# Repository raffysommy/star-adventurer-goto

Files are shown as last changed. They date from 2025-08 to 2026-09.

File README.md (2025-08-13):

# Star Adventurer Classic and 2i GoTo Mod

This project transforms a Sky-Watcher Star Adventurer or Star Adventurer 2i into a fully functional GoTo mount with guiding capabilities. It achieves this by adding a custom, Arduino-powered Declination (DEC) axis that works in tandem with the mount's native Right Ascension (RA) motor.

The system is controlled via a Python-based proxy server that emulates the Meade LX200 protocol, allowing you to control your modified mount from most popular planetarium or astrophotography software (like Stellarium, Cartes du Ciel) using INDI LX200 GPS driver (it may work on Windows too).

The core of this project relies on the [**advanced firmware**](https://skywatcher.com/post/resource/star-adventurer-advanced-firmware/) for the Star Adventurer (not needed for the 2i), which enables serial communication. This firmware is a bit buggy, and this project includes several software workarounds to ensure stable and reliable operation despite those quirks.

## Features

-   **Full GoTo Capability:** Slew to any celestial object from your favorite software.
    
-   **LX200 Protocol Emulation:** Wide compatibility with astrophotography software.
    
-   **Full Guiding Support:** Pulse guiding on both RA and DEC axes (via direct driving or  ST4).

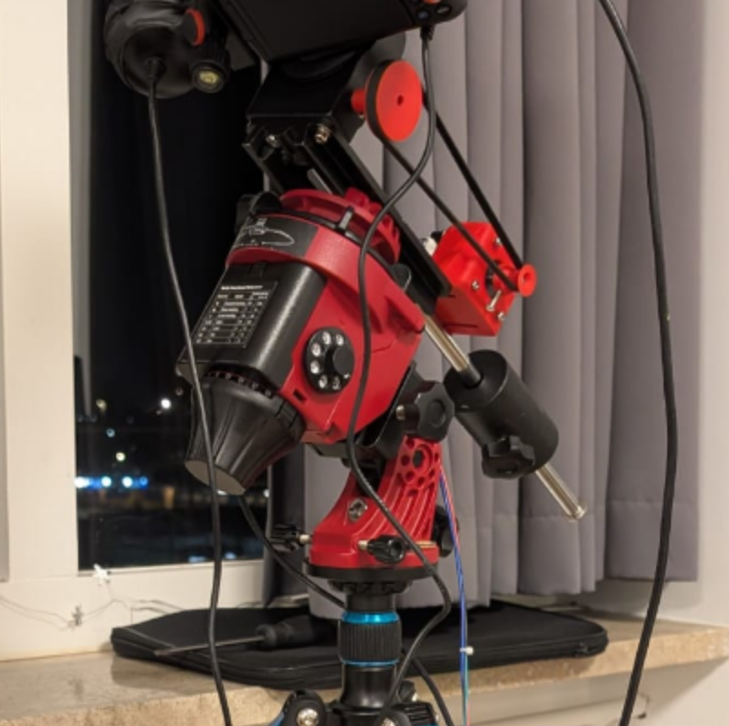
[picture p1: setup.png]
Setup


## 1. Hardware Requirements

### Electronic Components

The heart of the DEC axis is a simple circuit controlled by an Arduino Nano.

-   **Arduino Nano:** The microcontroller that runs the DEC motor logic.
    
-   **EasyDriver v4.5 (or similar):** A simple stepper motor driver.
    
-   **NEMA 17 Bipolar Stepper Motor:** The motor that drives the DEC axis.
    
-   **DC Female Power Jack:** To power the EasyDriver and motor (9-12V recommended). A step-up converter can be used if you are powering from a 5V source.
    
-   **(Optional) RJ12 Socket:** For a standard ST4 guiding port. The system also supports direct pulse guiding commands from your control software.

### 3D Printed Parts (`/stl` folder)

You will need to print the following parts to assemble the DEC axis.

-   `Nema17MotorHolder.stl`: Mounts the NEMA 17 motor to the Star Adventurer's DEC bracket.
    
    -   Requires: 4x M3 screws (for the motor) and 2x M5 screws with bolts (for the bracket).
        
-   `StarAdventurerDeclinationKnobMod.stl`: Replaces the original DEC knob on the Star Adventurer and connects to the timing belt.
    
    -   Requires: 1x small M2 screw to secure it.
        
-   `Nema17Knob.stl`: Attaches to the NEMA 17 motor shaft.
    
    -   Requires: 1x M3 screw and nut for tightening.

### Mechanical Parts

-   **GT2 Timing Belt (400mm loop, 6mm width):** Connects the motor to the declination knob.

## 2. Wiring and Assembly

The circuit connects the Arduino to the EasyDriver to control the stepper motor. It's crucial to ensure all ground connections (GND) are common between the Arduino, the EasyDriver, and the DC power supply.

-   **Power:** Connect your 9-12V DC power supply to the EasyDriver's power input (M+ and GND).
    
-   **Arduino to EasyDriver:**
    
    -   Connect Arduino **Pin D2** to EasyDriver **STEP**.
        
    -   Connect Arduino **Pin D3** to EasyDriver **DIR**.
        
    -   Connect Arduino **GND** to EasyDriver **GND** (the one near the power input).
        
-   **Motor to EasyDriver:** Connect the four wires of the NEMA 17 motor to the EasyDriver's motor outputs (OUT1A, OUT1B, OUT2A, OUT2B).

#### Circuit Diagram

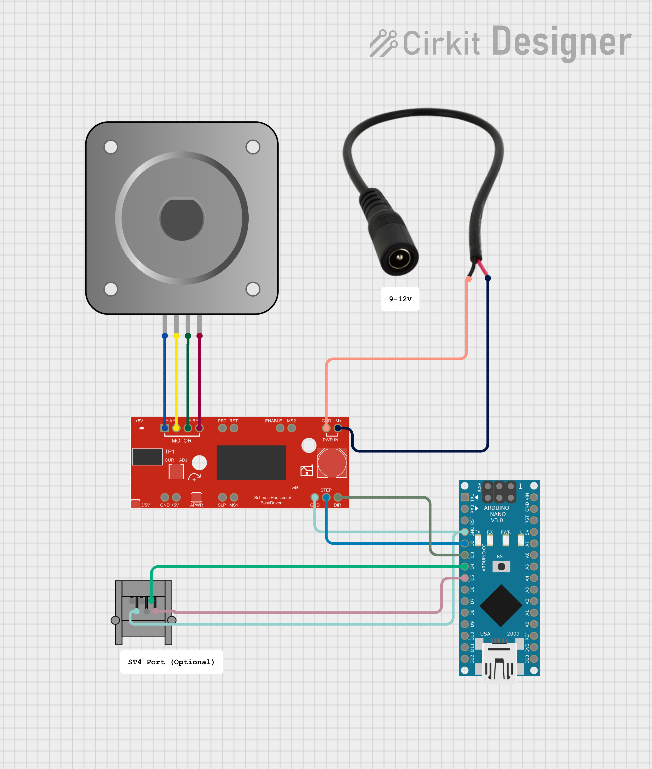
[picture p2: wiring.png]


## 3. Software Setup and Installation

### Step 1: Clone the Repository

First, clone this repository to your local machine.

```
git clone https://github.com/raffysommy/star-adventurer-goto
cd star-adventurer-goto

```

### Step 2: Set up the Arduino

1.  Open the Arduino IDE.
    
2.  Navigate to the `arduino` folder in this project.
    
3.  Open the `.ino` sketch file.
    
4.  Connect your Arduino Nano to your computer.
    
5.  Select the correct board (Arduino Nano) and COM/TTY port from the `Tools` menu.
    
6.  Upload the sketch to the Arduino.

### Step 3: Install Python Dependencies

It is highly recommended to use a Python virtual environment.

```
# Create a virtual environment (optional but recommended)
python -m venv venv
source venv/bin/activate  # On Windows use `venv\Scripts\activate`

# Install the required packages
pip install -r requirements.txt

```

## 4. Configuration

Before running the server, you must configure the Python script with your specific setup.

Open the `lx200.py` file and edit the following constants at the top:

-   **`SERIAL_PORT`**: Change this to the serial port your Arduino is connected to (e.g., `COM3` on Windows, `/dev/ttyUSB1` on Linux).
    
-   **`OBSERVER_LON`**: Set your observer's longitude in decimal degrees (East is positive).
    
-   **`OBSERVER_LAT`**: Set your observer's latitude in decimal degrees (North is positive).

**Initial Pier Side**: You may need to set your mount's starting pier side. In `new_lx200.py`, find the `TelescopeController` class and its `__init__` method. Set the `self.is_pier_east_side` variable according to your physical setup.
-- **Example:** Set `pier_east_side = False` (the default) if the  camera is on the side of the Star Adventurer with the mode dial and lights, with your camera pointing in the opposite direction of the celestial pole. Set it to `True` if the lights are on the other side or you are pointing towards the celestial pole. If you make it wrong the mount will move in the opposite direction, so just try to flip it :)

You may also need to adjust `step_per_rev_dec` if your motor or gearing setup is different.

## 5. Advanced Topics & Explanation

### The RA Slew Limitation and the "Virtual Meridian Flip"

The advanced firmware for the Star Adventurer has a critical limitation: the RA motor cannot perform a full 360-degree slew. It operates reliably only within a ~180-degree range of motion in software counters. If a GoTo command requires it to move beyond this range (i.e., to cross a "virtual bar"), the command will fail, and the mount will get stuck.

This script implements a "hack" to overcome this. We call it a **Virtual Meridian Flip**.

Here's how it works:

1.  When your planetarium software (e.g., KStarsr) sends a GoTo command, our Python proxy receives the target's RA and DEC coordinates.
    
2.  The script calculates the target's Hour Angle (HA), which determines its position relative to the meridian.
    
3.  The script checks if slewing to this HA would force the RA motor to cross its "forbidden zone".
    
4.  If it does, the script performs a "virtual meridian flip":
    
    -   It calculates a new RA target that is 180 degrees away from the original target's HA. This new target is within the motor's "safe" operational range.
        
    -   It simultaneously inverts the target DEC coordinate.
        
    -   It sends these _new, corrected_ coordinates to the mount's motors.

The result is that the telescope ends up pointing at the correct celestial object, but with the mount on the opposite side of the pier, completely avoiding the firmware limitation. This entire process is transparent to your control software, which believes it's communicating with a standard, fully-functional LX200 mount.

### Networking the Star Adventurer (for non-2i models)

The original Star Adventurer communicates via a serial (USB) port. The Star Adventurer 2i has built-in WiFi. For this system to work, the Python proxy script needs to communicate with the mount over a network connection.

-   **Star Adventurer 2i users:** You can skip this step. Simply connect to your mount's WiFi network.
    
-   **Original Star Adventurer users:** You must make the mount's serial port available on the network. The recommended tool for this on Linux-based systems (like a Raspberry Pi) is `ser2net`.

`ser2net` is a daemon that allows you to connect to a serial port over a TCP or UDP network socket.

**Example `ser2net` Configuration:**

You need to create or edit the `/etc/ser2net.yaml` file. Here is a sample configuration that exposes a serial device on `UDP port 1880`, which is what the `synscan` library expects.

```
%YAML 1.1
---
# This is a ser2net configuration file.
# Find detailed documentation in ser2net.yaml(5)

define: &banner \r\nser2net port \p device \d [\B] (Debian GNU/Linux)\r\n\r\n

connection: &con0096
    accepter: udp,1880
    enable: on
    options:
      kickolduser: true
      telnet-brk-on-sync: false
    connector: serialdev,
              /dev/ttyUSB0,
              115200n81,local

```

**Breakdown of the configuration:**

-   `accepter: udp,1880`: Listens for incoming UDP connections on port 1880.
    
-   `connector: serialdev, /dev/ttyUSB0, 115200n81,local`: Forwards all traffic from the network port to the serial device located at `/dev/ttyUSB0` with a baud rate of 115200. **You must change `/dev/ttyUSB0`** to match the actual device name of your Star Adventurer's USB-to-Serial adapter.

After configuring `ser2net`, you can enable and start the service using `systemctl`:

```
sudo systemctl enable ser2net
sudo systemctl start ser2net

```

## 6. Running the Proxy Server

Once everything is configured, run the main script from your terminal:

```
python lx200.py

```

If successful, you will see a message indicating that the proxy is listening for connections:

LX200 Proxy listening on 127.0.0.1:5000

The server is now running. You can now connect to it from your planetarium or astrophotography software by configuring it to use a **Meade** LX200 **GPS** telescope at **IP Address `127.0.0.1`** and **Port `5000`**.

Once connected, you can select objects and issue GoTo commands, and the mount will slew to the target

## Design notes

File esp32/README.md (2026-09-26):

# StarMount: ESP32-S3 mount controller

Firmware that turns an ESP32-S3 into the complete controller for the Star Adventurer
GoTo mod. It replaces the Raspberry Pi running `lx200.py` and the separate DEC
controller:

- **RA**: the Star Adventurer's own motor, over USB (the ESP is the USB host)
- **DEC**: the NEMA17 stepper on an EasyDriver, driven directly
- **Clients**: OnStep protocol over Wi-Fi, a superset of Meade LX200. INDI/Ekos and ASIAIR use their
  OnStep driver (pier side, meridian limits, backlash), NINA the ASCOM OnStep driver, and
  Stellarium, SkySafari and generic LX200 drivers work too. Plus a web dashboard.

## Hardware

| What | Details |
|---|---|
| Board | ESP32-S3 N16R8 (16 MB flash, 8 MB octal PSRAM) |
| RA link | Native USB port (OTG, GPIO19/20) ↔ mount's USB (Prolific PL2303 HXD, `067b:2303`), 115200 8N1 |
| VBUS | The ESP must supply 5 V on the OTG port: board powered from the 5V pin, "USB-OTG" pad bridged |
| DEC | EasyDriver: STEP GPIO6, DIR GPIO5, EN GPIO38 (active low, disabled while idle) |
| Ground | ESP, EasyDriver/12 V supply and mount share ground |

The OTG port belongs to the mount, so after the first flash **everything goes over Wi-Fi**:
updates, logs, control. The CH343 "UART" port shows the UART0 console if you can attach it.

## Build, flash, update

Needs PlatformIO ≥ 6.2 (the pioarduino platform, Arduino core 3.x / ESP-IDF 5.5, is pulled
in automatically).

```sh
cd esp32
# Wi-Fi credentials (git-ignored); without them the ESP opens AP "StarMount" / "starmount"
cat > secrets.ini <<'EOF'
[secrets]
build_flags = -DWIFI_SSID=\"MySSID\" -DWIFI_PASS=\"MyPassword\"
EOF

pio run -e usb -t upload            # first flash over USB (BOOT+RESET for download mode)
pio run -e ota -t upload            # later: ArduinoOTA to starmount.local
curl -F fw=@.pio/build/usb/firmware.bin http://starmount.local/update   # or HTTP upload
pio test -e native                  # host unit tests (no hardware)
```

**Recovery.** A new image that crashes before Wi-Fi comes up is meant to roll back to the previous
one, but it hasn't been checked that the bootloader actually has rollback enabled.
The USB host starts 10 s after boot, so OTA always has a window. Holding BOOT during that
window skips the USB host for one boot. Worst case: unplug the mount, BOOT+RESET, flash over USB.

**Tailscale / VPN.** If a VPN advertises the LAN subnet (Tailscale `--accept-routes`), traffic
to the ESP goes into the tunnel and it looks dead. Disable accept-routes, or bind to the
Wi-Fi interface (`curl --interface wlo1`, `STARMOUNT_IFACE=wlo1` for the tests).

## Interfaces

| Port / path | What |
|---|---|
| TCP 5001, 9999 | OnStepX-compatible commands (LX200 superset): see [docs/onstep-protocol.md](docs/onstep-protocol.md). 5001 is the old `lx200.py` port, 9999 OnStep's usual one |
| `http://starmount.local/` | Dashboard: RA/DEC, state, LST, clock, settings, DEC test buttons |
| `/api/status` | JSON state (used by the dashboard and the tests) |
| `/api/settings`, `/api/time`, `/api/home`, `/api/stop` | Settings, set clock from the browser, set RA home, stop |
| `/api/lx200?c=:GR` | Run one OnStep/LX200 command over HTTP |
| `/api/register`, `/api/goto_ha`, `/api/dec` | Debug: redefine the RA register, slew to a register angle, DEC test moves |
| TCP 10110 | NMEA over TCP: the GPS sentences, for INDI's "GPS NMEA" driver (KStars/Ekos time and location) |
| `/api/boots` | The last 10 boots (reset reason, how long the previous boot ran) and mount USB connects/disconnects, in NVS |
| `/api/tasks`, `/api/gps_nmea` | Per-task CPU/stack/heap; inject NMEA sentences (debug, no GPS needed) |
| `/log`, telnet 23 | Log (kept across resets: after a crash `/log` still shows the previous boot) |
| `/sys`, `/cmd?c=:e1`, `/update`, `/wifi` | System status, raw mount command, firmware upload, Wi-Fi setup |
| UDP 11880 | SynScan Wi-Fi-dongle compatible bridge to the mount (debugging only: it bypasses the RA controller) |

## Architecture

```
 clients:  INDI / NINA / ASIAIR / Stellarium / PHD2           browser
               │ OnStep (LX200 superset), TCP 5001 + 9999    │ HTTP
 ┌─────────────┴──────────────┐                  ┌───────────┴───────┐
 │ onstep_server              │                  │ dashboard         │  protocol
 │ parse, reply formats       │                  │ JSON API          │  front-ends
 └─────────────┬──────────────┘                  └───────────────────┘
 ┌─────────────┴──────────────┐
 │ mount: target, flip branch,│  one flip flag for the whole mount
 │ DEC reversal, guide, sync  │
 └──────┬──────────────┬──────┘
        │              │
 ┌──────┴──────┐ ┌─────┴──────┐        ┌───────────────────────────────┐
 │ ra_axis     │ │ dec_axis   │        │ lib/core/astro (pure C++)     │  pure logic,
 │ task + queue│ │ FastAccel- │ ◄────► │ LST, HA/RA, meridian flip,    │  host-tested
 │ tracking,   │ │ Stepper    │        │ DEC steps, OnStep parse/format│
 │ goto, guide │ └─────┬──────┘        └───────────────────────────────┘
 └──────┬──────┘       │
 ┌──────┴──────┐       │           services: clock (NTP / LX200 / browser → later GPS),
 │ skywatcher  │       │                     settings (NVS), netlog, OTA
 │ protocol    │       │
 ├─────────────┤       │
 │ mount_usb + │   EasyDriver
 │ pl2303      │   (DEC motor)
 └──────┬──────┘
    USB OTG → Star Adventurer (RA)
```

Design rules:

- **One owner per motor.** The `ra_axis` task is the only code that sends RA motion commands.
  Everything else posts requests to its queue, so commands can't interleave (that was
  `lx200.py`'s `ra_locker` and its "junk data" workarounds). `mount_usb` serializes the
  request/response pairs underneath.
- **Protocols are thin front-ends.** `onstep_server` only parses and formats. The mount-level
  state (target, meridian-flip branch, guide flags) lives in `mount`, shared by every
  front-end, so there is one flip flag whatever the client.
- **Math lives in `lib/core`** with no Arduino dependencies. It is unit-tested on the PC against
  golden values produced by `lx200.py`'s own functions (`test/gen_golden.py`).
- **Guiding is never disturbed.** Pulses change only the RA step period while the motor keeps
  running. DEC pulses are exact step moves. Recovery from firmware auto-stops uses a bare
  `J`, never a stop/restart.
- **Cores:** Wi-Fi, lwIP and USB host on core 0; RA/DEC/OnStep server on core 1. DEC step pulses come from hardware.

Planned additions: GPS (time, site, magnetic declination), a 9-axis IMU in the base box
(polar axis altitude and heading) and a 6-axis IMU on the camera hot shoe (mechanical pose,
push-to, pier side, safety limits), plus fast polar alignment in tiers from sky-less
(~0.5–1°) to two plate solves (~1′). The design is in
[docs/sensors-and-alignment.md](docs/sensors-and-alignment.md).

## Star Adventurer firmware quirks (measured)

| Quirk | Handling |
|---|---|
| Motion mode `G` is two digits: `1x`=tracking slow, `3x`=tracking fast; `x0`=CW, `x1`=CCW (the fix in the modified pysynscan) | `sw::setMode` |
| `G` is refused (`!2`) while the motor runs | stop, poll `:f` until stopped, then G → I → J |
| Max RA speed ≈ 0.28°/s (~68× sidereal); T1 below ~6 or fast mode is not faster | slews use slow mode, T1 = 5 |
| At slew speed, CW auto-stops after ~0.8 s; after any direction reversal both directions stop after ~0.5 s | `J` re-sent every 400 ms during slews; in tracking, `:f` polled every 250 ms and a bare `J` sent if stopped |
| Register below 0 → tracking stalls every second; above ±241.7° the 24-bit register overflows | GoTo/sync targets limited to HA 2°–183° (`offset_star_adventurer` = 2°), overflowing register values refused |
| At power-on the mount starts tracking by itself, so the register isn't exactly 0 | a register within 1° of 0 = fresh mount → set to home (HA 2°) |

## Differences from lx200.py

- **LST is correct.** `lx200.py` gives ephem the longitude as a float (read as radians) and local
  time as UTC, so its sidereal time is off by a constant (~93° plus the timezone). A sync hid this
  for RA, but HA-based decisions moved: **the meridian flip now happens at the true meridian.**
- `:SG/:SL/:SC` set the clock (the Pi had its own). `:Sg/:St` parse signs correctly. `:GG` uses the
  Meade sign convention.
- `:MS`/`:CM` without a prior valid `:Sr` don't move or sync RA.
- **The protocol is OnStepX's** (since 2026-09-26), not `lx200.py`'s dialect. Set commands answer
  `1`/`0`, `:CM` answers `N/A#`, stops and pulses answer nothing, and `:GVP#` is `On-Step`.
  Standard LX200 clients don't notice. Tracking can be turned off (`:Td`/`:Te`).
- DEC guide pulses are exact step counts, not timed stops (those overshot by the queued steps).
- RA guide/slow-move directions follow ASCOM/EQMOD: west = 1.5×, east = 0.5× sidereal (`lx200.py`
  had them swapped). Redo PHD2 calibration made with the old firmware.
- DEC guide rate is 0.5× sidereal (1.7 steps/s). `lx200.py`'s "sidereal" 6.796 steps/s was really 2×.
- DEC backlash is compensated (below), and DEC GoTos always end moving north (+steps).
- **RA window and flip.** The register window starts at a configurable east limit (dashboard, NVS
  `ra_east`, default 0 = `lx200.py`'s flip at the meridian; −30 = flip 2 h before it). register =
  HA − east limit + 2°. GoTos use the window [2°, 182°] on either branch (`lx200.py` flipped at 180,
  leaving a 2° dead zone). Tracking goes on past the window and **stops at register 235°**, before
  the 24-bit overflow. Changing the east limit shifts the register so the position keeps its meaning.
- **Branch choice happens at use, not at `:Sr`.** `:MS` takes the window's branch, and `:CM` keeps
  the branch nearest the current register (a sync doesn't move the mount). Before, a sync past the
  window flipped the maths without moving: the old beyond-the-pole bug. DEC steps are computed then
  too, so the `:Sr`/`:Sd` order doesn't matter. The flip flag survives OTA and crash resets.
- The RA register survives ESP restarts (read back from the mount). The DEC position survives soft
  resets and OTA (kept in RAM). After a power-on DEC starts at 0° (146400 steps), as `lx200.py` did.

## Measured on the sky (2026-09-25, plate solves through a window)

M50 + 70-200 @ 200 mm (3.9″/px), astrometry.net 4100 indexes, scripts in `tools/sky/` (prototypes: ESP IP and `wlo1` are hard-coded in `pa.py`; run them from `$HOME`, gphoto2 is a snap)
(`pa.py`: polar alignment from two solves around an RA move; `mount_tests.py`: DEC, sync,
GoTo, guide, drift; `pe_record.py`: RA drift from live-view frames, no shutter).

| What | Result |
|---|---|
| DEC backlash | ~250 steps (0.30–0.34°) on every reversal, reproducible |
| DEC scale | 805 steps/° on one clean move (nominal 813.3) |
| RA/DEC orthogonality | 89.8° |
| RA GoTo after sync | 0.5–3′ (limited by the RA drift below) |
| DEC GoTo after sync | before: ~1′ if ending north, 17–18′ if ending south; with compensation: 0.4–1.4′ both ways |
| DEC guide pulses | before: the first ~4 pulses after a reversal did nothing; now the first one overshoots ~2× once, then settles |
| RA guide pulses | 0.45–0.6× sidereal (nominal 0.5×) |
| RA tracking (unguided, 10 min, 1 frame/min) | register exactly sidereal, but the sky wanders ±60″ — mechanical |
| RA periodic error (live view, 22 min, ~7 fps) | **±30″ sine at the worm period (~10 min)**, cycles correlate 0.89, 7″ rms non-periodic left. Max slope 0.3″/s: PHD2 + Predictive PEC; no firmware PEC (no worm index, phase lost at power-on) |

**DEC backlash model.** `dec_axis` keeps the motor position and the gear output apart: the gear
sits within `[motor − backlash, motor]` and only moves when pushed. Everything reported and
targeted is the gear position. On a reversal the play is run out at slew speed (guide pulses
included, so PHD2 sees no dead zone). `backlash` is a setting (dashboard, NVS key `dec_bl`,
default 250 steps); lowering it softens the one-pulse overshoot after a reversal.

## PEC, limits and GPS (2026-09-26)

- **PEC**, OnStep-style (`:$QZ+ - / Z ! ?`, `:VR`/`:WR`, `:GXE6/7/8`; the INDI OnStep PEC tab):
  - The table has one correction per worm segment (~1 sidereal s; 599 segments of 86,751 counts
    per 144-tooth worm turn), in register counts.
  - **Record** takes RA guide pulses for one worm turn (turn PHD2's Predictive PEC off). It is
    smoothed, its mean removed, and averaged with the previous table.
  - **Play** changes the RA step period each segment and carries the rounding into the next
    segment, so a whole turn is exact despite the coarse T1.
  - **Worm phase** follows every register rewrite (sync, home, east limit) and is saved to NVS
    every 10 s. After a power-on it is restored, on the assumption that the worm didn't turn
    while unpowered.
  - **Playback only starts after 60 s without guide pulses**, so PHD2 never sees PEC switch on mid-guiding.
- **Limits**:
  - GoTo is refused below the horizon limit (`:Sh`, code `1`) and above the overhead limit (`:So`, `2`).
  - Tracking stops `raWestMinutes` past the meridian on the flipped branch (`:SXEA`, default
    120, capped by the overflow). `:SXE9` sets the east limit.
- **GPS** (boilerplate until the module is wired: UART1 RX 17 / TX 18, 9600, any NMEA RMC+GGA):
  - Time is trusted below NTP and above clients.
  - A fix with ≥4 satellites and HDOP < 5 sets the site.
  - `:GU#` reports `S` while the GPS keeps the clock.
  - The sentences are relayed on TCP 10110.
  - Tested by injection.
- **Resources** (measured, guiding plus a client polling 10× faster than INDI):
  - core 0 6% busy, core 1 18% busy
  - 157 KB internal heap free, PSRAM unused

## Rates, refraction, limits (2026-09-26)

- **Tracking rates:**
  - sidereal, lunar, solar, King and custom (`:TQ :TL :TS :TK :ST`); not saved, sidereal at boot
  - The base is now true sidereal (`lx200.py`'s 0.004176 was a fixed "refracted" slow-down).
  - **Calibrated:** the SA's register runs at exactly timerHz / T1, within ±0.04% from T1 280 to
    439 (`test/hil/rate_calibration.py`, data in `rate_calibration.csv`). The earlier "lunar
    0.36% slow" and PEC's 1.04 gain were laptop-side HTTP timing. Rate tests now use the ESP's
    own register-read timestamp (`counts_ms` in `/api/status`).
- **Refraction** (`:Tr`/`:Tn`, default on, RA only; `:T2` dual axis is not supported):
  - Every 10 s the rate is scaled by d(apparent HA)/d(true HA) at the current pointing
    (Saemundsson's formula).
  - Examples: 0.99975 on the meridian at Dec +20, about 0.9985 at 20° altitude in the west.
- **Guide rate** is one setting for both axes (`:SX90,n#`, dashboard, 0.1–0.9×, default 0.5).
  - DEC backlash can be set from the client (`:$BD[arcsec]#`). RA backlash only accepts 0.
- **Axis limits** (`:GXEe/w` RA window in axis hour angle, `:GXEC/D` DEC mechanical, set with `:SXEx,n#`):
  - A GoTo past a DEC limit is refused with code `6`.
  - Manual moves stop at the limit, and guide pulses are clamped.
  - This is the counts-based layer of the collision limits.
- **PEC start rule** (default *strict*): playback starts only before guiding begins for the
  target (no pulse since boot or the last GoTo); otherwise it waits for the next GoTo.
  - Option: after 60 s without pulses.
  - A table recorded with a different segment count (it changed from 599 to 598 with true
    sidereal) is not loaded: record again.

## Manual moves and boot log (2026-09-27)

- **Manual moves** use OnStep's `:R0`–`:R9` (0.25×, 0.5×, 1×, 2×, 4×, 8×, 20×, 48×, half max, max;
  Meade `:RG :RC :RM :RS`):
  - RA below 1× changes only the tracking speed.
  - RA from 1×, the motor runs west (forward) or east (reversed) with the slew keep-alive.
    Max is ~64× measured, half max ~32×.
  - After a reversal the SA auto-stops once, and the tracking watchdog restarts it within seconds.
  - DEC runs up to 256× with the backlash take-up and axis limits.
  - Moves stop at the register limits, and abort a PEC recording.
- **Boot log** (`/api/boots`, shown on `/sys`), in NVS:
  - the last 10 boots: reset reason (`BROWNOUT` = rail sag, `power-on` = supply off), and how
    long the previous boot ran (saved every 5 min)
  - the last 10 mount USB connects/disconnects
  - Flash wear: one record per boot or event, plus 288 small writes a day.
- The PEC phase is now saved every 30 s, and only while a table exists.

## RA without a register limit, persistent state (2026-09-27)

- **Axis angle vs register.** The model (GoTo window, branch choice, sync, limits) works in
  the axis angle (= hour angle − east limit + 2°). The SA's register is bookkeeping:
  - register = axis angle + a persisted shift
  - It is re-centred to 8° whenever the motor is stopped anyway: sync, home, the start and end
    of a GoTo (a slew longer than the band re-centres mid-way).
  - **Never while tracking:** after ~15 h without a GoTo or sync, tracking stops at the band
    end instead of disturbing guiding.
  - The only RA limits are physical: the east limit, and the west tracking stop
    (`raWestMinutes`, default 120 = axis angle 242° with −30°; max 240 min).
- **Register writes are verified**: wait for the stop, write, read back, retry up to 3 times
  with a hard stop. The SA rejects `:E` while still stopping. It was seen twice in 20 writes
  after fast moves, and before this fix a sync could silently not apply. A write that still
  fails marks the position untrusted.
- **Sync keeps the branch nearest the current axis angle** (within 20°), even past a limit.
  Before, a sync exactly at the tracking stop picked the other branch.
- **Persistent state** (`persist.h`): one versioned struct in RTC memory holds the DEC
  position, the flip flag, the RA shift and "position trusted". It survives OTAs of *new*
  firmware (separate no-init variables moved whenever unrelated code changed), with no flash
  wear. It's lost on power-off, which resets the mount too.
- **Position trusted** (dashboard "NOT SYNCED"): false after a power-on (assumed home) or a
  failed register write, true after a confirmed sync.
- DEC continuous moves are bounded moves to the axis limit (exact stop even at 256×).

## Tests

- `pio test -e native`: astro math, DEC steps, parsing. Regenerate golden values with
  `python3 test/gen_golden.py` (needs `ephem`).
- `test/hil/` (hardware in the loop, against a running ESP and mount):
  - `guide_soak.py [N]`: random N/S/E/W pulse guiding; checks both axes moved exactly as
    commanded and that the RA motor was never restarted
  - `goto_test.py`: sync, then two combined RA+DEC GoTos and back. **Moves the mount.**
  - `pec_test.py`: records a synthetic periodic error from simulated guide pulses (one worm
    turn), checks the table, plays it back and checks that the register follows it (~17 min, RA tracking only).
    2026-09-26: table correlation 0.978, playback correlation 0.999, gain 1.04, 5.4 counts rms residual.
  - `features_test.py`: tracking rates, refraction, guide rate, backlash, DEC axis limits and
    the strict PEC rule (~3 min, small moves)
  - `rate_calibration.py`: RA register rate vs raw T1, timed on the ESP (~2.5 min per point)
  - `move_test.py`: manual-move speeds `:R0`–`:R9` on both axes (small moves, ~1 min)

  ```sh
  cd test/hil && STARMOUNT_HOST=starmount.local STARMOUNT_IFACE=wlo1 python3 guide_soak.py
  ```

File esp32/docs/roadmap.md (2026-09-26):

# Roadmap (as of 2026-09-26)

What's done, what to test on the sky, what to build next. The details are in
[sensors-and-alignment.md](sensors-and-alignment.md) (MEMS, alignment, collisions) and
[onstep-protocol.md](onstep-protocol.md) (the protocol).

## Done

- **Protocol:** OnStepX-compatible front-end (LX200 superset) on TCP 5001 and 9999, tested with
  the real INDI OnStep driver. It covers:
  - pier side
  - meridian and axis limits
  - backlash
  - PEC
  - tracking rates and refraction
  - GPS time/site (boilerplate)
- **RA:** a configurable register window (east limit −30° set; flip from 2 h before to ~1.5 h
  after the meridian), a tracking stop, and a sync that keeps the branch.
  - The register rate was calibrated: exactly timerHz/T1.
- **DEC:** backlash compensation (250 steps), GoTos finishing northward, 0.5× guide rate, axis limits.
- **PEC:** record from guide pulses, playback, the phase kept in NVS, and the strict start rule
  (never switches on under an active guider).
- **Sky tools** (`tools/sky`): polar alignment from two solves (`pa.py`), mount tests, a live-view
  periodic-error recorder. Measured: ±30″ worm PE (598 s), polar alignment down to ~11′.

## Next clear night (no new hardware)

1. **Re-sync first.** The mount was powered off since, and the DEC NOINIT position is lost
   whenever a firmware build changes the memory layout.
2. **Clearance check before the first GoTo east of the meridian** (east limit −30° is already set):
   - Camera body ~22° below horizontal on the east side and ~17° on the west side.
   - Swing the lens through its whole DEC range.
   - If anything touches: a smaller east limit, plus DEC axis limits on the dashboard.
3. **Ekos + PHD2 with the "LX200 OnStep" driver** (TCP `starmount.local:9999`):
   - Calibrate, then check PHD2's Guiding Assistant backlash against our 250 steps.
   - Go through a real meridian flip, and check that PHD2 flips its calibration from the reported pier side.
4. **Record a real PEC table:**
   - PHD2's Predictive PEC off, guide ≥1 worm turn (10 min), then Record in the INDI PEC tab or on the dashboard.
   - Next night: enable Play before starting guiding, and compare the RA RMS with and without it.
5. **NINA through the ASCOM OnStep driver** (Windows): connect, GoTo, sync, flip.
6. More DEC scale samples: one clean move gave 805 steps/° vs 813.3 nominal.

## Small firmware items (no hardware needed)

- ~~Reset-reason log~~: done 2026-09-27 (`/api/boots`, `/sys`). The "OTA power dips" of 2026-09-26
  were the user powering off. The 2026-09-23 offline event is still unexplained, and the log
  will tell next time.
- ~~Manual-move speeds~~: done 2026-09-27 (`:R0`–`:R9`, `test/hil/move_test.py`).
- PEC phase verification: after a power-on the restored phase is trusted as it is. It should be
  fitted against the first minutes of guiding without PEC (the first target of the night; PEC
  then plays from the next GoTo), and PEC refused if it doesn't match.
- ~~No register limit~~: done 2026-09-27 (axis angle vs register, re-centred only at stops,
  never while tracking; verified register writes; persistent-state struct).

## When the hardware arrives

Order from the design doc:
1. **GPS (GY-GPS6MV2)** on UART1: RX 17 ← GPS TX, TX 18 → GPS RX, 9600 baud. The firmware is ready:
   - check `/api/status` → `gps`
   - install `indi-gpsnmea` and point it at `starmount.local:10110`
   - test time in the field without NTP (`:GU#` shows `S`)
2. **Pi alignment tool:** turn `tools/sky/pa.py` into the T3/T2 tool (INDI + ASTAP + the ESP), with a live mode for turning the knobs.
   - Add a branch check at every sync from the solve's field rotation (180° apart on the two branches).
3. **Camera IMU (MPU6500, hot shoe)** on its own I2C bus: SDA 1, SCL 2, pull-ups at the ESP end.
   - mechanical pose at power-on and branch detection without sky
   - hand-slew detection and push-to
   - collision layers: accelerometer tilt rules, gyro stall detection during slews, taught limits
   - possibly exposed as OnStep "encoders"
   - **automatic DEC backlash and scale at startup** from the gyro (see the calibration table in the design doc)
4. **Base box IMU + magnetometer (LSM6DSV + QMC6309)**, I2C0 SDA 8 / SCL 9:
   - T0 polar alignment
   - knob feedback
   - tripod-bump detection
   - leveling (the tripod isn't level: turning the base changes the axis altitude)
5. Later / optional:
   - park and home from the IMU pose
   - pointing model from several syncs
   - BME280 for refraction and dew warnings
   - auto meridian flip once the collision limits exist

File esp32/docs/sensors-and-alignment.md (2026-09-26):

# Sensors, pose awareness and polar alignment

Design notes: what GPS and two IMUs can add to the ESP32 mount controller, what they
can't, and how they fit with the motor counts and plate solving. Nothing here is
implemented yet. See [README](../README.md) for what exists today.

## Goals

- **Pointing awareness:** a mount that knows where it is pointing, after assembly, after hand moves, on either side of the pier.
- **Fast manual pointing:** move it by hand (the RA motor tops out at ~0.28°/s, so 90° takes over 5 min) and let the ESP work out where it is.
- **Quick polar alignment good enough for guiding,** without the slow Ekos procedure. Precision on demand.
- **Never disturb tracking or guiding.**
- **Don't modify the Star Adventurer:** everything attaches outside (its USB port, the DEC knob belt, the battery bay).

## Constraints

- **The rig is disassembled for every trip.**
  - Nothing mechanical survives transport, so there's no fixed home and no park position to remember.
  - Only calibrations of *rigid* parts carry over.
- **Camera:** Canon M50 on a 70–200 at 200 mm. APS-C gives ~6.4° × 4.3° at ~3.8″/px.
  - The lens is held by its **tripod collar**, whose foot is screwed tightly to the DEC bracket's moving plate (minimal yaw).
  - The camera and lens can rotate *inside* the collar ring.
- **Clutches:** both can be released (RA on the Star Adventurer, DEC on the bracket), so both axes can be moved by hand.
- **Imaging host:** a Pi running INDI/Ekos, with ASTAP available for plate solving.
- **Polar alignment is manual:** the altitude and azimuth knobs have no motors, so "self alignment" means *guided* adjustment. Only motorised adjusters would make it automatic.
- **Power:** a USB-C power bank with a PD trigger set to 9 V.
  - 9 V feeds the EasyDriver directly.
  - A step-down converter feeds 5 V to the ESP, the Star Adventurer (through the OTG port's VBUS), the GPS and the IMUs.

## Hardware and placement

| Part | Where | Role |
|---|---|---|
| ESP32-S3, EasyDriver, GY-GPS6MV2 (u-blox NEO-6M), **LSM6DSV + QMC6309** magnetometer (one breakout) | **Base box**, ideally a keyed 3D-printed insert in the (empty) battery bay. That's the fixed body of the Star Adventurer, which tilts with the polar axis | Controller, time and site, polar-axis altitude and heading |
| **MPU6500** (6-axis) | **Camera hot shoe** | Mechanical pose of both axes, plate-solve-calibrated |

### IMU choices

- **Base: LSM6DSV + QMC6309.**
  - ~5× lower accelerometer noise and much lower temperature drift than the MPU6500, which keeps the magnetometer's tilt compensation accurate. Needed for sky-less polar alignment (T0 below).
  - A current part from real suppliers.
- **Camera: MPU6500 is enough.**
  - Its temperature drift (~0.5–1 mg/°C, up to ~0.5° over a night) is compensated with **its own on-chip temperature sensor**.
  - The model is learned from plate solves, and every solve re-anchors it.
  - The LSM6DSV's temperature wouldn't help: it measures the base box, not the lens.
- **Avoid the MPU9250.** It's discontinued, most boards sold as MPU9250 are clones or relabelled MPU6500/9255 dies without a working magnetometer, and even genuine ones have MPU6500-class accelerometers.

### Camera IMU placement: hot shoe vs collar ring

| | Hot shoe | Collar ring / foot (keyed clip) |
|---|---|---|
| IMU ↔ camera | Fixed. **Every plate solve calibrates the IMU directly** (offsets, temperature model) | Changes when the camera is rotated in the collar |
| IMU ↔ DEC axis | Changes with the collar rotation. **Re-measured per session by a short DEC move** (~10° in 10 s, gyro or two solves) | Fixed, calibrated once |
| Single-picture PA (T1) and IMU learning | Direct | Needs the camera ↔ collar roll per session |

**Decision: hot shoe**, with an automatic short DEC move at startup.
- If the camera is rotated in the collar during the night, the gyro sees a rotation about the optical axis while the motors are idle, and the ESP re-measures.
- The cable crosses both axes either way: leave a loose loop with slack for DEC passing the pole.

### Other hardware notes

- **EasyDriver stays.** It's disabled almost all night (a few slews, short guide pulses), so heat and power are not a concern, and the camera has never slipped with DEC unpowered.
  - A TMC2209 would be optional: silent, cool, holding current, StallGuard for belt-slip or collision detection.
  - Keep the IMU away from the driver chip anyway.
- **Magnetometer environment:** the EasyDriver's coil currents, the Star Adventurer's RA motor, the ESP, and the DEC motor (**permanent magnet**) and counterweight bar, which rotate with RA.
  - Sample only with the DEC driver disabled, at a fixed reference RA angle.
- **GPS:** the patch antenna faces the sky, away from the ESP's antenna and the driver.
- **Travel connectors:** latching and impossible to plug in wrong.
  - RJ12 (6-wire, like the ST4 cable) for the camera IMU.
  - JST or small aviation connectors for the DEC motor and power.
- **Box extras:** an RGB status LED (tracking, slewing, guiding, error, GPS fix) and a physical **STOP** button that stops both axes without needing Wi-Fi.
- **Not planned:**
  - hall sensors / home switches (the IMUs replace "home", and they'd need magnets on the mount)
  - opening the Star Adventurer
  - motorised alt/az adjusters: only for truly automatic alignment, as a separate unit under the mount

### Electrical plan (proposed pins)

| Function | Bus | Pins |
|---|---|---|
| GPS, NMEA 9600 | UART1 | ESP RX 17 ← GPS TX, ESP TX 18 → GPS RX (TX optional, for configuring it) |
| LSM6DSV + QMC6309 (base, short wires) | I2C0, 400 kHz | SDA 8, SCL 9 |
| MPU6500 (camera, long cable) | **I2C1 (its own bus)**, 100 kHz | SDA 1, SCL 2; 2.2–4.7 kΩ pull-ups at the ESP end; twist SDA with GND if possible |
| Already used | | USB 19/20, DEC 5/6/38 |
| Avoid | | 0/45/46 (strapping), 35–37 (octal PSRAM), 43/44 (UART0) |

- **Why the camera IMU gets its own bus:** a long cable crossing both axes is the most likely thing to glitch or hang an I2C bus. On its own bus, a flaky or unplugged camera IMU can't take the base sensors down.
- **Firmware must:** recover the bus and handle hot-unplug.

## Power: the power-bank risk

PD power banks can:
1. **Switch off at low load**, typically below ~50–150 mA. At night the EasyDriver is off and the ESP plus a tracking Star Adventurer draw little at 9 V, close to that threshold.
2. **Briefly reset all ports** when another device is plugged or unplugged, or when the charge negotiation changes.

Either one is a **power loss**, which is worse than a reboot:
- **The Star Adventurer's RA register restarts at 0**, and today's "fresh mount" logic would assume home (HA 2°), **silently wrong**.
- **The DEC position is lost.** It only survives soft resets, because it's kept in RAM.

**Mitigations:**
- Give the mount its own bank (or at least its own port), and don't charge a phone from it.
- Use the bank's low-current / always-on mode if it has one; otherwise add a small constant load (e.g. the status LED) to stay above the threshold.
- **Firmware:** detect a power-on reset mid-session and **mark the position untrusted** ("power lost: re-sync") instead of assuming home. With the camera IMU, the pose is recovered automatically.

**5 V rail:** the Star Adventurer's motor current flows through the step-down and the dev board's OTG pad trace.
- The buck should deliver at least 2–3 A.
- Measure the 5 V at the board during a RA slew once. It should stay above ~4.8 V.

**Suspected cause of the unexplained offline event on 2026-09-23:** the ESP stayed unreachable for minutes. A firmware hang would have tripped the task watchdog and rebooted within ~15 s, so a power cut is more likely. `/log` shows the reset reason on the next boot (1 = power-on).

## What each sensor physically gives

| Sensor | Gives | Realistic accuracy | Limits |
|---|---|---|---|
| GPS (NEO-6M) | UTC time, latitude and longitude, offline; **magnetic declination** via the World Magnetic Model | Time ±0.1 s from NMEA (= 1.5″ of RA); declination ±0.3–0.5° | Needs sky view; first fix takes a while. PPS is on the board's LED if ever needed |
| Accelerometer | Direction of gravity = **2 of 3 orientation angles**, absolute, no drift | LSM6DSV ~0.05–0.1°; MPU6500 ~0.1–0.2° with temperature compensation | Can't see rotation about the vertical (azimuth) |
| Gyro | Rotation while moving (hand slews, the direction of a rotation axis) | Good over seconds | Drifts, so short-term only |
| Magnetometer | Heading | ~0.5–1° absolute with care (error budget below); ~0.1–0.2° *relative* over minutes | Dominated by the rig's iron and currents, not by the chip |

### Magnetometer heading: error budget

| Source | Size | Mitigation |
|---|---|---|
| Magnetic vs true north | ~4° here | GPS position + World Magnetic Model: ±0.3–0.5° |
| Tilt compensation | Accelerometer error × ~1.5 (the field dips ~56° at this latitude) | LSM6DSV: ~0.1–0.15° (the MPU6500 would give ~0.5°) |
| Fixed rig iron (Star Adventurer body and RA motor, EasyDriver, ESP) | Several degrees | Hard/soft-iron calibration of the **fully assembled rig**, turned through a full circle on the ground once. Leaves ~0.3–0.5° |
| Parts rotating with RA (counterweight bar, lens, NEMA17 magnet) | Varies with the RA angle | Always measure at the same RA angle, with the EasyDriver off |
| Tripod/wedge steel moving when the azimuth knob turns | Small | Mostly negligible |
| Box heading axis vs polar axis | Fixed offset | Calibrated once against a plate-solve alignment (T3). Stable thanks to the keyed battery-bay insert |

**Total: ~0.5–1° absolute**; better relative while turning a knob.

## Polar alignment accuracy actually needed (200 mm, guided)

| Polar alignment error | Max DEC drift | Field rotation at the frame corner (~3.9° off-centre) in a 2-min sub | Verdict |
|---|---|---|---|
| 1′ | ~0.3″/min | negligible | ideal |
| 0.5° | ~8″/min | ~1″ (< 1 px at 3.8″/px) | **workable**: PHD2 handles the drift |
| 1° | ~16″/min | ~2″ | borderline, OK for 1–2 min subs |

Stacking handles rotation *between* subs. Longer focal lengths or longer subs need the precise tiers below.

## Polar alignment tiers

| Tier | Needs | Estimated accuracy | Time |
|---|---|---|---|
| **T0: no sky** | Base IMU (altitude) + magnetometer + GPS declination (azimuth) | 0.5–1° | ~1 min, live feedback on **both** knobs |
| **T1: single picture** | 1 solve + both IMUs + mechanical model (DEC axis in camera frame from the startup DEC move) | ~0.3–0.6° | Free at the first solve; re-checked at every later solve |
| **T2: two pictures, DEC move** | 2 solves ~10° apart **in DEC (the fast axis)** + base IMU altitude + one-time bracket calibration | ~0.1–0.2° | ~20 s |
| **T3: two pictures, RA move** | 2 solves + the exactly known RA rotation | ~1′ | ~1 min |

T1 and T2 are estimates on paper and need measuring. The magnetometer's remaining offset is **learned from every T3 run** and stored, so T0 improves from session to session.

### Why a single picture alone isn't enough (T1)

- **What a solve gives** (with GPS time and site): the camera's full orientation, including which way it faces.
- **What we need:** which way the *base* (the polar axis) faces.
- **What gravity gives:** the relation between camera and base in tilt, but **not in rotation about the vertical**. That's exactly the azimuth we're after.
- **How it's closed:** the mechanical chain (RA rotation → DEC rotation → camera on the DEC axis). With the camera's mounting on the DEC axis known (measured by the startup DEC move), the camera IMU gives the RA and DEC angles. That fixes camera ↔ base completely, and one solve gives the polar axis in the sky.
- **Accuracy:** limited by the IMUs and the mechanical model (RA/DEC non-orthogonality, cone error). Hence ~0.3–0.6°.

### T2: second picture via DEC

- **Measurement:** two solves ~10° apart in DEC give the DEC axis on the sky precisely.
- **Constraints on the RA axis:** it is perpendicular to the DEC axis (the bracket's small non-orthogonality is calibrated once against T3), and its altitude comes from the base IMU.
- **Result:** at most two solutions, and the IMUs pick the right one.
- **Why it's fast:** DEC moves at ~1°/s, so no slow RA rotation is needed.

### T3: second picture via RA (precise)

- **Why Ekos is slow:** its polar alignment treats the mount as a black box and solves 3 frames about 30° apart, roughly 60° of RA travel. That's ~3.5 min of motion at ~0.28°/s, before the adjustment loop.
- **What we use instead:** the ESP knows the RA rotation between two frames to ~0.1″ (12.5 M counts per revolution).
- **The method** (from any starting pose):
  1. Take frame 1 and plate-solve it.
  2. The ESP rotates RA by an exactly known angle Δ (5–10°).
  3. Take frame 2 and plate-solve it (with the first solve as a hint).
  4. The image centre moved along a small circle around the RA axis. Two points plus the known Δ give the circle's centre, which **is the RA axis on the sky**.
  5. The error is the vector from that axis to the celestial pole, with refraction applied.
- **Precision:** solves at 3.8″/px are good to ~1–2″. With Δ = 5° the axis comes out at **~1′**; periodic error adds up to ~1′.
- **Time:** 18–36 s of rotation, plus two 2–4 s exposures and two ASTAP solves. **~1 min.**
- **Special case:** if the camera points near the pole, matching stars between the frames gives the rotation's fixed point even more precisely.

### Adjustment feedback while turning the knobs

- **Altitude knob:** the base IMU, instant and live.
- **Azimuth knob:**
  - the magnetometer, instant (relative ~0.1–0.2°), or
  - images: 1–2 s exposures, re-solved with a hint or tracked by star shift, every few seconds (Ekos "refresh" without the slow part).
- **End:** one confirmation solve.

### Where it runs

- **Pi:** a companion Python tool. It captures frames through INDI (to confirm: the M50 via the GPhoto driver) and solves them with ASTAP. It drives the ESP through a new `/api/pa` endpoint: rotate RA or DEC by an exact amount and report the counts.
- **ESP dashboard:** results and live knob feedback.
- The ESP never handles images.

### Practical notes

- Tape the 70–200's zoom ring: zoom creep at steep angles changes the image scale between frames.
- At 70 mm the field is ~18°×12°: solving is easier, but T3 comes out ~3× coarser (~3′).
- **Quick check before building anything:** lower the rotation in Ekos's polar alignment from 30° to 10°.

## Pose awareness: "where the mount is"

### 1. Mechanical pose: always, from power-on

- **What's measured:** camera IMU + base IMU give the RA angle (counterweight), the DEC angle, pier side and over-the-pole, at ~0.5°. No sky, no alignment.
- **This replaces "home":** no more assuming HA 2° / DEC 0° at power-on.
- **Two candidate poses:** for some orientations gravity allows two mechanical solutions.
  - They are always far apart.
  - The gyro's motion history picks the right one, or failing that "counterweight roughly down" at power-on.
  - The ESP flags the rare cases it can't resolve.

### 2. Sky pointing: depends on how well the polar axis is known

| Stage | Polar axis known from | Sky pointing accuracy |
|---|---|---|
| Just assembled | T0 (base IMU + magnetometer + GPS) | ~1° |
| After polar alignment | T1–T3 | ~0.5–1°, live, everywhere |
| After the first plate solve of the night | Camera IMU re-anchored | ~0.3–0.5°, re-anchored at every solve |

### Calibrations

| Calibration | How | How often |
|---|---|---|
| Base IMU → polar axis | Rotate RA 60–90° and fit the cone traced by the camera IMU's gravity vector (its axis is the polar axis). Compare with the base IMU at the same moment | Once, while the box sits in its keyed insert |
| Camera IMU → camera (offsets, temperature model) | Every plate solve: predicted vs measured gravity in the IMU frame | Continuous, learned over nights |
| DEC axis in the camera frame | Short DEC move at startup (gyro, or two solves) | Each session, and when the camera is rotated in the collar |
| **DEC backlash and scale** (auto) | The same startup move, ±1–2°. After a reversal, the motor steps counted until the gyro sees the camera turn = backlash (at 100–200 steps/s, well above gyro noise; repeat and average). Rotation vs steps = steps/°. Steps with no rotation beyond the backlash = slip | At startup for a first value, then **at every GoTo**. The DEC approach always ends with a small reversal (overshoot ~100 steps), done after RA has arrived and at ~200 steps/s: zero extra moves, measured in each target's pose and load, refreshed after flips. Use only the gyro component about the DEC axis. Keep a running average with outlier rejection; accept only 100–500 steps. Never from guide pulses (below gyro noise) or while guiding |
| RA/DEC non-orthogonality (bracket) | Against a T3 run | Once |
| Magnetometer (hard/soft iron) | Fully assembled rig turned through a full circle once, at a reference RA angle | When the box layout or site changes |
| Magnetometer heading offset | Learned from each T3 run | Continuous |

### Which side of the pole: one solve is enough

The 360° DEC axis reaches every patch of sky on two branches: normal, or with DEC swung past the pole (after a meridian flip).
- The two branches see the same sky **rotated by 180°**, so a single plate solve's field rotation tells them apart.
  - On 2026-09-25 image +x pointed at position angle ≈ 1.3° on the normal branch. The other branch would read ≈ 181°.
  - Remounting the camera a few degrees off each trip doesn't matter against 180°.
- **Calibration:** once, the camera's rotation on the bracket, from a solve on a known branch.
- **Check at every sync:** if the solve's rotation disagrees with the branch the ESP assumes, refuse the sync and say so. That's exactly the old beyond-the-pole failure, caught before the first wrong GoTo.
- **Without sky:** the camera accelerometer does the same. On the two branches, for the same pointing, the camera is rolled 180°, so gravity sits on opposite sides of the camera frame.
- The DEC-move test (the sign of ΔDec for +steps) also works, but costs a move and two solves.

## RA register window (implemented 2026-09-26; east limit −30 set; register limit removed 2026-09-27, see the README)

**Today:** register = HA + 2° (`OFFSET`, from `offset_star_adventurer`), and GoTo/sync are limited to register 2°–183°.
- This keeps clear of both register failures: below 0 tracking stalls, and above 241.7° the 24-bit value overflows.
- The consequence is that only the western sky is reached directly. Everything east of the meridian is a meridian flip (RA +180°, DEC 180 − Dec).
- The narrow window was chosen when a Raspberry Pi drove the mount over USB, for fear of overflow if the Pi disconnected while the mount kept tracking.

**Why it can move now:**
- The ESP is on the mount itself, sees the register continuously, and enforces limits at every poll.
- If the ESP dies, the mount keeps tracking on its own at 15°/h. With the west limit kept ~59° below overflow, that still leaves the same ~4 h of margin as today.

**Proposal (chosen: east limit −30°):**

| | Now | Proposed |
|---|---|---|
| Register | HA + 2° | HA + 32° (east limit as a setting; register = HA − east limit + 2°) |
| Normal branch (no flip) | target HA +0° … +181° | target HA **−30° … +150°** (register 2°–182°) |
| Flipped branch | target HA −180° … 0° | target HA −210° … −30° |
| Where the flip happens | at the meridian | 2 h **before** the meridian |
| Margin to overflow at the west limit | 59° (~4 h) | 59° (~4 h) |

**The window must stay 180° wide.**
- The normal branch covers the axis window, and the flipped branch covers the same window shifted by 180°.
- Narrower than 180°, some targets are reachable on neither branch. So the west limit moves with the east limit.

**Behaviour:**
- Every target crossing the sky still needs **one** flip somewhere, since the window is 180°. The offset only chooses **where**, and the flip point is the east limit.
- With −30°, anything you start within 2 h before the meridian, or any time after it, never flips. That covers transit, the best part of the night.
- A target started earlier (more than 2 h east) starts on the flipped branch and flips once, at HA −30° instead of at the meridian.
- The flip itself is unchanged: a real GoTo to the other branch, triggered by the client re-slewing (NINA/Ekos "meridian flip" set to 2 h before the meridian, i.e. −30°).
- **Tracking past the window** (implemented): tracking continues to register 235° and stops there. A flipped-branch target can track from 2 h before the meridian to ~1.5 h after it, and you flip (re-slew) whenever it suits you.
- **Overflow margin:** the mount is powered from the ESP's OTG port, so it can't keep tracking with the ESP dead. The 4 h margin is no longer needed.
- **The register limit could go entirely:** a software offset, with a ~1 s pause between subs to shift the register back near the end of the span. The only limits would then be collisions and cables.
- **Sync keeps the branch** (implemented): `:CM` picks the candidate nearest the current register, so solve → sync → GoTo ("center") never flips the maths without a move.

**Before doing it:**
- **East of the meridian on the normal branch, the camera sits below the RA head** (on a classic mount, the counterweight-up position). This is where the lens can hit the head or a tripod leg.
  - So the east limit (−60°) must be a **setting**, set from a real clearance check with the rig.
  - The collision limits below should exist first.
- **Home at power-on** (register near 0 → "HA 2°") changes meaning. It must be restated for the new offset, or replaced by the IMU pose.
- Update the golden tests (`test/gen_golden.py` uses lx200.py's offset) and the flip logic (`selectTarget`), and document it as a deliberate difference from lx200.py.

## Collision limits

Collisions are geometric: the lens or body against the SA head, the tripod legs, or the base box. They depend on the full mechanical pose (RA angle, DEC angle), not on which branch we're on.

| Layer | How | Needs |
|---|---|---|
| **Configured limits** | Forbidden zones in mechanical coordinates (RA register, DEC motor angle). A GoTo whose path enters one is refused or rerouted | A one-time **teach**: move slowly toward each obstacle, press "mark limit" on the dashboard, and the ESP stores the counts, plus the IMU pose when there is one |
| **Accelerometer** (camera) | Gives the camera's tilt directly: "lens pointing below −10°" or "camera upside down under the head" are simple, absolute rules. It works even when the counts are wrong (after a hand slew, a lost sync, a wrong branch) | Nothing beyond the planned MPU6500. It can't see rotation about the vertical, but the counts or the base IMU supply that |
| **Gyro** (camera): stall or collision detection | During a slew the ESP knows the commanded rate (up to 0.28°/s RA, 870 steps/s DEC). If the gyro reads ~0 while the motor should be turning, something is blocking or slipping: stop within ~0.5 s | The same MPU6500. Only active during slews (guiding rates are far below the gyro noise) |
| **Driver** (optional) | A TMC2209 with StallGuard on DEC | A driver swap |

- **The IMU layers are a safety net for when the model is wrong.** A wrong sync, a wrong branch or a hand slew are exactly the cases where count-based limits fail.
- The stop rules follow "When the IMU may act": stop at once during slews; during tracking, warn first and only stop at a hard limit.

## Hand-slew and push-to workflow

1. Pick a target (e.g. Andromeda) on the phone dashboard.
2. Release the clutches and swing the lens. **Push-to:** the dashboard shows a live arrow and the remaining distance ("12° up, 30° left… 0.5°, lock").
3. Lock the clutches. When the camera IMU is still, the ESP sets its registers to the new pose.
4. Plate solve and sync (the Pi tool); the IMU supplies the pier side.
5. A short motor GoTo centres the target.

## Sensor fusion, authority and interference

### Who's in charge (from most to least trusted)

1. **Plate solve:** precise, absolute. Always wins and re-anchors everything.
2. **Motor counts** (RA register, DEC steps): precise, relative. They run tracking and guiding.
3. **IMUs:** coarse, absolute. Advisory by default.

Guide corrections are arcseconds; the IMUs resolve ~0.2–0.5°. **The IMUs cannot see guiding.**

### When the IMU may act

| Situation | Signature | Action |
|---|---|---|
| Hand slew (clutch open) | Camera IMU rotates fast (≫ 1°/s), base still, motor counts unchanged | After ~2 s of stillness: update the registers to the new pose |
| Camera rotated in the collar | Rotation about the optical axis, motors idle, base still | Re-measure the DEC axis in the camera frame (short DEC move, when not guiding) |
| Slow drift or disagreement | IMU and counts drift apart by a fraction of a degree over minutes | **Nothing to the mount.** Dashboard estimate only; the next solve re-anchors |
| Tripod bumped | **Both** IMUs jump together | Alert: "mount bumped, alignment/sync may be off". No register change |
| Tripod settling in azimuth | T1 estimates drift between solves | Alert only |
| Suspected DEC belt slip | DEC steps vs camera IMU disagree by more than ~1° | Alert only. Never stops guiding by itself |
| Power loss mid-session | Power-on reset while a session was active | Position marked untrusted; recovered from the IMUs, confirmed by the next solve |
| Collision limit | Pose past a limit (lens toward the tripod, counterweight far up) | During **slews**: stop. During **tracking**: warn first, stop only at a hard limit, and only if it holds for over 1 s and agrees with the pose predicted from the counts |

Built-in protections:
- **An RA register rewrite needs the motor stopped.** The Star Adventurer only accepts `:E` when stopped, so RA can't be rewritten mid-tracking. It is only done after a detected hand slew, which interrupted tracking anyway.
- **While guiding is active** (pulses within the last ~minute), every automatic IMU action is disabled except the hard collision stop. Alerts only.
- **An "IMU authority" setting:** *off* / *advisory* (default: estimates, push-to, alerts) / *auto* (adds hand-slew register updates and collision stops).

### Other kinds of interference

- **Electrical** (long cable, EasyDriver noise, I2C glitches):
  - Readings are sanity-checked: gravity ≈ 1 g, plausible gyro rates, the bus responds.
  - A bad sensor is marked **invalid** and the ESP carries on without it.
  - The camera IMU has its own bus.
  - The magnetometer is sampled only while the DEC driver is off and has no authority.
- **Timing:**
  - Sensor reading runs in a low-priority task.
  - The RA control task, the guide-pulse timers and the DEC step pulses (generated in hardware) have priority and are independent.
- **Mechanical** (wind, touching the lens): readings are filtered, and a pose counts only when the mount is still.

**Worst case:** the IMU is wrong. In advisory mode the only symptom is a wrong push-to arrow or a false alert. Guiding is never touched.

### Tests to add

- The existing `test/hil/guide_soak.py` must still give **0 RA motor restarts** with the IMUs running.
- A new HIL test that simulates a tripod bump, a hand slew and a camera rotation in the collar, and checks the reactions against the table above.

## Session flow (target)

1. **Assemble:** counterweight roughly down, roughly north; the box goes into the battery bay.
2. **Power on:**
   - GPS gives time and site.
   - The IMUs give the mechanical pose.
   - A short automatic DEC move measures the camera mounting.
3. **T0 polar alignment:** turn both knobs with live feedback to ~0.5–1°. Often enough at 200 mm.
4. **First solve:** T1 check and camera IMU calibration. Refine with T2/T3 if needed.
5. **Point:** by hand with push-to, or by motor GoTo; plate-solve sync; centre.
6. **Track and guide:** the IMUs are advisory only.
7. **Disassemble:** nothing to save except the rigid calibrations.

## Priorities

Before any sensor work:

1. **Read `/log` about the offline event;** check the power bank's behaviour and the 5 V rail.
2. **Field networking:** decide whether the ESP joins the Pi's hotspot or the Pi joins the ESP's access point. The clock comes from the LX200 client or the browser until the GPS exists.
3. **DEC soft limits** (configurable) and **power-loss detection** (untrusted position after a mid-session power-on).
   - Collision limits by teach (counts first, the IMU later).
   - A branch check from the solve's field rotation at every sync.
   - **RA register window** (HA −30°…+150°) and the stop at the tracking limit: done 2026-09-26. Set the east limit to −30 on the dashboard after a clearance check on **both** sides: camera under the head east of the meridian, and on the flipped branch past it.
   - Log the reset reason to NVS: on 2026-09-26 an OTA attempt apparently power-cycled the mount (it came back fresh after only a software reset), and a power-on wipes the RAM log.
4. **Night test** with INDI "LX200 GPS" + PHD2, watching:
   - the meridian flip (now at the true meridian)
   - the `"0"` reply to `:Mg`
   - `:GG`
   - hours of tracking and guiding
5. **Mount simulator:** a simulated Star Adventurer with its quirks (CW auto-stop, stop after reversal, stall below zero, 24-bit overflow), so the RA state machine and the IMU authority logic can be tested on the PC.

Then the sensor roadmap:

1. **GPS:** offline time, site and declination. It also solves the field clock.
2. **Pi alignment tool** (T3, then T2): INDI + ASTAP + ESP `/api/pa`, including "solve and sync".
3. **Camera IMU (MPU6500, hot shoe):** mechanical pose at power-on, pier side, hand-slew detection and push-to, collision limits, belt-slip alerts, T1.
4. **Base IMU + magnetometer (LSM6DSV + QMC6309):** T0, knob feedback, tripod-bump detection.
5. **Later / optional:**
   - an OpenAstroMount/OAT-compatible LX200 front-end
   - motorised alt/az adjusters
   - a pointing model (cone error from multiple syncs)

## Open questions

- Does the M50 capture through INDI's GPhoto driver in the current Ekos setup?
- How the collar clip or hot-shoe adapter and the camera IMU cable are routed across both axes.
- Battery-bay insert design: does the base box fit in the bay, keyed and repeatable?
- Power bank model: low-current mode, and behaviour when other ports are used?

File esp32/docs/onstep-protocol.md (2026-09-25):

# OnStep front-end: the command subset

**Status (2026-09-26):** implemented in `src/onstep_server.cpp`, replacing the LX200 front-end.
Tested with the real INDI OnStep driver against the ESP: connect, sync, GoTo there and back,
guide pulses, moves, tracking off/on, time, location. Pier side reached INDI. The HIL guide soak
passes on port 5001. Not yet tested: Ekos + PHD2 across a real flip, NINA (ASCOM).

Goal: an OnStepX-compatible protocol front-end on the ESP, next to the LX200 one, so that
INDI (Ekos, ASIAIR) and ASCOM (NINA) use their **OnStep drivers**. Those drivers understand
pier side, meridian limits, backlash, PEC and park, which the generic LX200 protocol can't
express. The biggest gain is pier side: PHD2 then flips its DEC calibration on its own after
a meridian flip, so no recalibration is needed.

## How this list was made (2026-09-26)

- The **real INDI OnStep driver** (`indi_lx200_OnStep`, INDI 2.2.0) was pointed at a logging
  stand-in (`tools/onstep/stub.py`).
- It was driven through connect, GoTo, sync, guide pulses, manual moves, abort, tracking on/off
  and track rate, time, location, park and unpark (`tools/onstep/actions.py`).
- The capture is `tools/onstep/capture-indi-2.2.0.log`.
- Reply formats come from the **OnStepX firmware source**, taken as the reference
  implementation (github.com/hjd1964/OnStepX, 2026-09-08).
- Unknown commands get `0`: OnStepX's own "error / not supported" reply, with no `#`.

**The key finding: "not supported" isn't always safe.** Where the driver expects a
`#`-terminated string (`:Gc#`, `:GM#`, `:GtH#`, `:%BD#`…), a bare `0` makes it wait 2–5 s
per command and reconnect. Those commands need their real reply, even if it's a dummy value.

## Connection and identification

| Command | Reply | Notes |
|---|---|---|
| ACK (0x06) | `G` | German mount |
| `:GVP#` | `On-Step#` | The product name. The driver sends it twice at connect |
| `:GVN#` | `10.26a#` | The version decides the driver's behaviour: a `10.` prefix = OnStepX, with high precision on |
| `:GVD#` / `:GVT#` | `Sep 08 2026#` / `12:00:00#` | Firmware date and time |
| `:Gc#` | `24#` | Clock format. **A string reply is required** |
| `:GM#` `:GN#` `:GO#` `:GP#` | `Site 1#` … | Site names. **A string reply is required** |
| `:GT#` | `60.16427#` | Tracking rate in Hz (`0` when not tracking) |
| `:Gt#` `:GtH#` | `+40*52:22#` / `+40*52:22.000#` | Latitude, from the GPS once it exists |
| `:Gg#` `:GgH#` | `-014*26:16#` | Longitude, **west positive** (Meade) |
| `:GG#` `:GL#` `:GC#` | `-02:00#`, `HH:MM:SS#`, `MM/DD/YY#` | UTC offset, local time, date |

Probed once and answered "none", which is fine:
- `:FA#`, `:F1A#`…`:F9A#` (focusers) and `:fA#` (rotator): `0`
- `:GX98#`: `N#` (no rotator)
- `:GXY0#` (auxiliary features): `0`

## Status poll (every poll period, ~3 s by default)

| Command | Reply (ours) | Meaning / maps to |
|---|---|---|
| `:GU#` | e.g. `NpEW220#` | Status letters, see below |
| `:GR#` `:GD#` | `HH:MM:SS.SSSS#`, `sDD*MM:SS.SSS#` | High precision, since OnStepX reports it |
| `:Gm#` | `E#` `W#` `N#` | **Pier side.** INDI → `TELESCOPE_PIER_SIDE` → PHD2 |
| `:%BD#` `:%BR#` | `n#` arcsec | DEC/RA backlash. `dec_bl` 250 steps ≈ 1100″ |
| `:GX90#` | `0.50#` | Pulse-guide rate (× sidereal) |
| `:GX95#` | `0#` / `1#` | Automatic meridian flip |
| `:GX96#` | `E#` `W#` `B#` | Preferred pier side (B = best) |
| `:GXE9#` `:GXEA#` | minutes, `n#` | **Minutes past the meridian allowed, east / west.** This is our register window (east limit, tracking stop) |
| `:Gh#` `:Go#` | `-10*#`, `85*#` | Horizon and overhead limits: where the collision limits will live |
| `:GX9A#` | `0` | Temperature. `0` = no weather sensor, so the driver skips `:GX9B#`…`:GX9F#` |

**`:GU#` letters** (OnStepX `Status.command.cpp`), in this order:
- `n` = not tracking; `N` = no GoTo in progress. Tracking = `N` without `n`; slewing = no `N`.
- Park state: `p` not parked, `I` parking, `P` parked, `F` park failed.
- `H` at home, `S` PPS/GPS synced (later, from the GPS), `G` pulse guide active, `g` guide active.
- `a` auto meridian flip.
- `R` PEC recorded; PEC state `/` ignore, `,` ready to play, `~` playing, `;` ready to record, `^` recording.
- Mount type `E` = GEM. Pier side `o` none, `T` east, `W` west.
- Then three digits: pulse-guide rate index, guide rate index, error code.
- Quirk: the INDI driver also reads the pier-side `W` as an old PEC flag and shows "PEC: Autorecord". Real OnStepX has the same issue; it's cosmetic.

`:Gu#` (bit-packed status) exists in newer OnStepX. The driver only uses it if supported, and a
`0` keeps it on `:GU#`.

## Motion and settings (captured)

| Action | Command(s) sent | OnStepX reply | Maps to |
|---|---|---|---|
| GoTo | `:Sr17:30:00.00#` `:Sd+10*00:00.0#` `:MS#` | `1`, `1`, then `0` = accepted (`1`… = error codes) | Same as LX200 `:MS` |
| Sync | `:Sr…#` `:Sd…#` `:CM#` | `N/A#` on success, `En#` on failure | Same as LX200 `:CM` (keeps the branch) |
| Pulse guide | `:Mgn0500#`, `:Mgw0700#` | nothing | `dec::guidePulse` / `ra::guide` |
| Slew rate | `:R4#` | nothing | Manual-move speed |
| Manual move | `:Mn#` … `:Qn#`, `:Me#` … `:Qe#` | nothing | `:Mn/:Me` / `:Q` per axis |
| Abort | `:Q#` | nothing | Stop |
| Tracking off / on | `:Td#` / `:Te#` | `1` = ok, `0` = failed | RA stop / start tracking |
| Track rate | `:TL#` (lunar), then `:GT#` | `1` | Only sidereal is supported: answer `0` for the others |
| Time | `:SG-02:00#` `:SL03:00:00#` `:SC09/26/26#` | `1` each | Clock (GPS later) |
| Location | `:Sg345:33:44.28#` `:St+40:52:22.08#` | `1` each | Site (GPS later) |
| Park / unpark | `:hP#` / `:hR#` | `1` / `0` | No park position yet: answer `0` (fails cleanly) |

**Parser requirements, more than the LX200 front-end handles today:**
- Fractional seconds in `:Sr`/`:Sd`/`:St`.
- **`:Sr17:23:60.00#`:** the driver rounds up to 60 seconds, so a seconds value of 60 must carry over.
- Longitude as `DDD:MM:SS.ss`, 0–360, west positive.

## Implementation notes

- **It replaces the LX200 front-end** instead of sitting next to it: OnStepX is a superset of the
  LX200 set. It is served on 5001 (the old port) and 9999.
- **Also answered** for generic LX200 clients:
  - `:U#` precision toggle: low `HH:MM.T` / `sDD*MM`, default `HH:MM:SS`, highest via `:GRH#`/`:GDH#`
  - `:Gr#`/`:Gd#` target, `:GA#`/`:GZ#` alt/az, `:GS#` sidereal time
  - `:CS#` sync without a reply, `:TQ#` sidereal
- **Meridian limits:**
  - `:GXE9#` = −east limit × 4 (minutes before the meridian allowed on the normal branch)
  - `:GXEA#` = (TRACK_MAX − offset − 180) × 4 (minutes after the meridian on the flipped branch)
  - With −30°: 120 and 92.
- `:MS#` answers `9` (unspecified) without a target, and `:CM#` answers `E6#` if the sync is refused.
- `:GU#` error digit: `7` (hardware fault) while the RA mount isn't connected.

### Added 2026-09-26

| Commands | Reply | Notes |
|---|---|---|
| `:$QZ+#` `:$QZ-#` `:$QZ/#` `:$QZZ#` `:$QZ!#` | nothing | PEC play / stop / record / clear / save (INDI's PEC tab) |
| `:$QZ?#` | `I` `p` `P` `r` `R`, plus `.` when the worm phase is known | Status: ignore, ready to play, playing, ready to record, recording |
| `:VR[n]#` / `:VR#` / `:WR[n,sn]#` | `sn#` / `sn,n#` / nothing | Table entry (register counts), current segment, write an entry |
| `:GXE6#` `:GXE7#` `:GXE8#` `:VW#` `:VS#` | numbers | Counts per sidereal second, per worm turn, segments |
| `:Sh[sDD]#` `:So[DD]#` | `1`/`0` | Horizon (−30..30) and overhead (60..90) limits, enforced on GoTo (`:MS#` → `1`/`2`) |
| `:SXE9,[n]#` `:SXEA,[n]#` | `1`/`0` | Minutes past the meridian: east limit (shifts the register window) and west tracking stop |
| `:GU#` | adds `S`, `R` and the PEC state character | GPS time sync, PEC recorded, `/,~;^` |

### Added 2026-09-26 (2)

| Commands | Reply | Notes |
|---|---|---|
| `:TQ#` `:TL#` `:TS#` `:TK#` `:ST[H.H]#` | `1` | Sidereal / lunar / solar / King / custom rate (Hz). `:GT#` reports it |
| `:Tr#` `:Tn#` `:T1#` | `1` | Refraction on / off, single axis. `:T2#` (dual axis) and `:To#` answer `0` |
| `:SX90,[n.n]#` | `1`/`0` | Guide rate for both axes, 0.1–0.9× (non-standard set; `:GX90#` reports it) |
| `:$BD[n]#` `:$BR[n]#` | `1`/`0` | DEC backlash in arcsec. RA accepts only 0 |
| `:GXEe#` `:GXEw#` `:GXEB#` `:GXEC#` `:GXED#` | `n#` | RA axis limits (axis hour angle, deg; `B` in hours), DEC mechanical limits |
| `:SXEe,n#` `:SXEw,n#` `:SXEC,n#` `:SXED,n#` | `1`/`0` | Set them (non-standard in OnStepX, where they are compile-time) |
| `:MS#` | adds `6` | Target outside the DEC axis limits |
| `:GU#` | `rs` with refraction on, else `(` `O` `k` for lunar / solar / King | |

## Next

1. Ekos + PHD2 across a real flip, to check that PHD2 flips its calibration from the pier side.
2. NINA through the ASCOM OnStep driver.
3. When the GPS is wired: check INDI's GPS NMEA driver on `starmount.local:10110`, and GPS time in the field (no NTP).

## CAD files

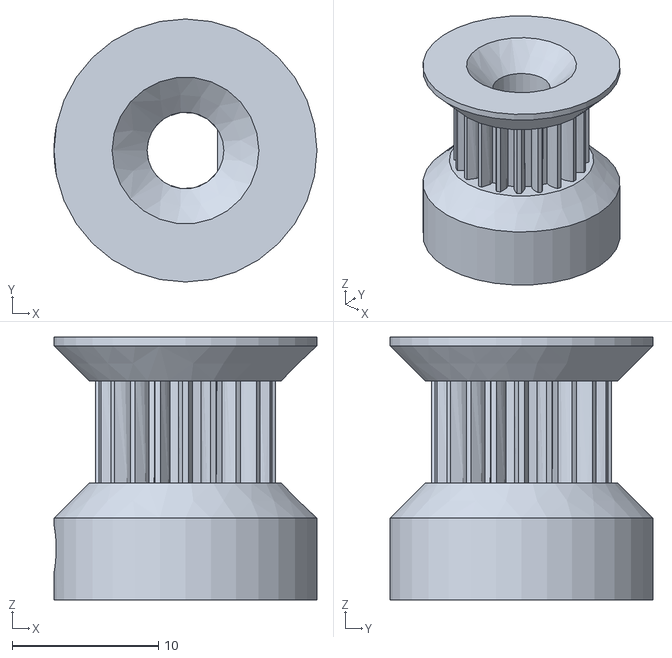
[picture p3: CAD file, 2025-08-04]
stl/Nema17Knob.stl
18.0 x 18.0 x 18.0

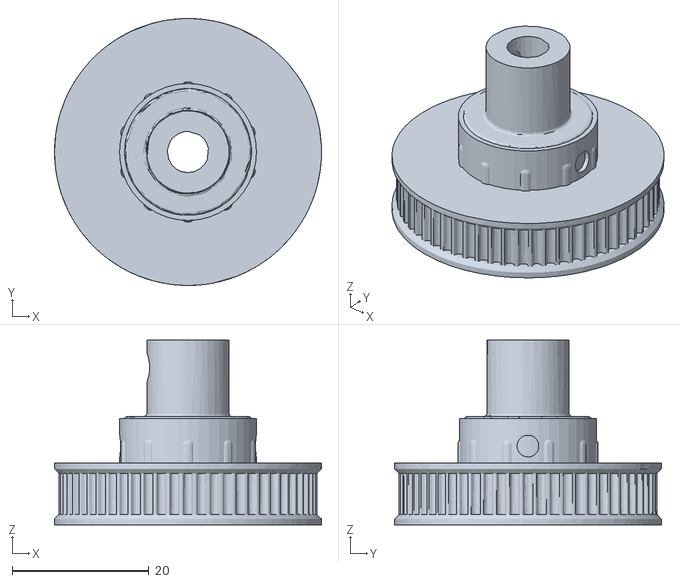
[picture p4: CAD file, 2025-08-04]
stl/StarAdventurerDeclinationKnobMod.stl
39.0 x 39.0 x 27.0

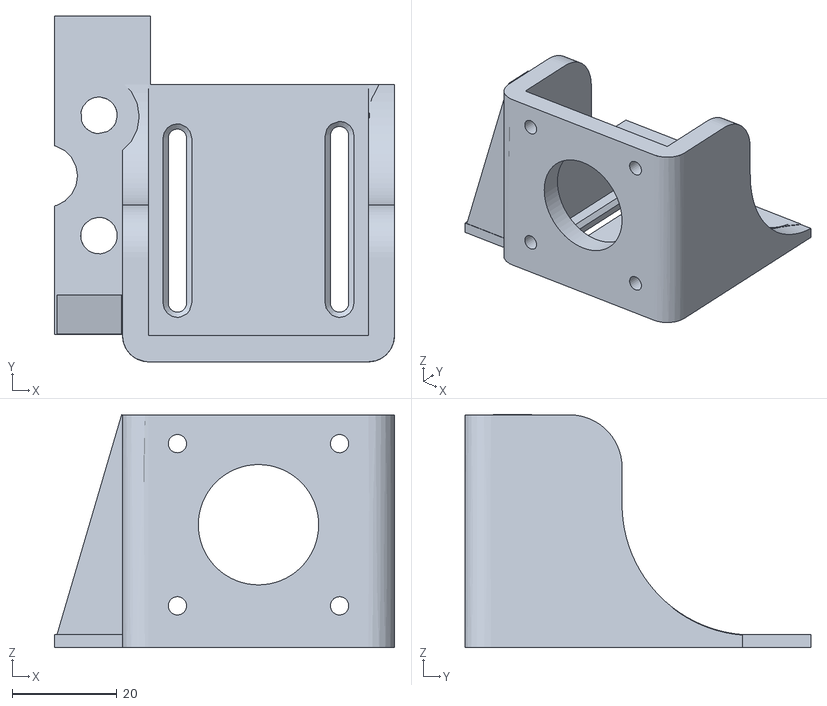
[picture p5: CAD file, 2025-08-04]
stl/Nema17MotorHolder.stl
65.0 x 66.1 x 44.6

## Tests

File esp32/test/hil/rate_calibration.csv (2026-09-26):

t1 | cps | samples
280 | 222.6334 | 48
287 | 217.1752 | 47
300 | 207.8149 | 47
330 | 188.9026 | 48
360 | 173.0846 | 48
400 | 155.8438 | 48
415 | 150.2281 | 48
421 | 148.0096 | 47
425 | 146.6926 | 48
428 | 145.6430 | 47
430 | 145.0030 | 47
432 | 144.3065 | 47
435 | 143.2972 | 47
439 | 141.9587 | 47

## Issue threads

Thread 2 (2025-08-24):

problem while compiling lx200.py

Yogilours, 2025-08-24:
Hello,

I tried to follow all the instructions but at the very end there seems to be a problem with the synscan module.

Have you exprerienced that before ?  (I changed all the TTY/USB1 to COM3 in the lx200py file)

Here is the error message I get :

(venv) C:\Users\Guillaume\star-adventurer-goto>python lx200.py
Traceback (most recent call last):
  File "C:\Users\Guillaume\star-adventurer-goto\lx200.py", line 50, in <module>
    arduinodec = serial.Serial('COM3', baudrate=115200)
  File "C:\Users\Guillaume\star-adventurer-goto\venv\Lib\site-packages\serial\serialwin32.py", line 33, in __init__
    super(Serial, self).__init__(*args, **kwargs)
    ~~~~~~~~~~~~~~~~~~~~~~~~~~~~^^^^^^^^^^^^^^^^^
  File "C:\Users\Guillaume\star-adventurer-goto\venv\Lib\site-packages\serial\serialutil.py", line 244, in __init__
    self.open()
    ~~~~~~~~~^^
  File "C:\Users\Guillaume\star-adventurer-goto\venv\Lib\site-packages\serial\serialwin32.py", line 64, in open
    raise SerialException("could not open port {!r}: {!r}".format(self.portstr, ctypes.WinError()))
serial.serialutil.SerialException: could not open port 'COM3': FileNotFoundError(2, 'Le fichier spécifié est introuvable.', None, 2)

Have you experienced that ?

Best regards

Guillaume

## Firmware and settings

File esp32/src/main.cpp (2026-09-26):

// Star Adventurer ESP32-S3 controller - phase 1: USB-host bridge + OTA + network log
#include <Arduino.h>
#include <ArduinoOTA.h>
#include <ESPmDNS.h>
#include <Preferences.h>
#include <Update.h>
#include <WebServer.h>
#include <WiFi.h>
#include <esp_ota_ops.h>
#include <esp_task_wdt.h>

#include "bootlog.h"
#include "clock.h"
#include "dashboard.h"
#include "dec_axis.h"
#include "gps.h"
#include "mount.h"
#include "onstep_server.h"
#include "mount_usb.h"
#include "netlog.h"
#include "persist.h"
#include "ra_axis.h"
#include "settings.h"
#include "synscan_udp.h"

#define HOSTNAME "starmount"
#define AP_SSID "StarMount"
#define AP_PASS "starmount"
#define BOOT_BUTTON 0
#define RECOVERY_WINDOW_MS 10000

#ifndef WIFI_SSID
#define WIFI_SSID ""
#endif
#ifndef WIFI_PASS
#define WIFI_PASS ""
#endif

static Preferences prefs;
static WebServer web(80);
static bool usbHostActive = false;

// Keep the new image in "pending verify" until Wi-Fi + OTA are up; if it
// crashes before that, the bootloader rolls back to the previous image.
extern "C" bool verifyRollbackLater() { return true; }

// ---------------------------------------------------------------- Wi-Fi

static void wifiBegin() {
  prefs.begin("wifi", true);
  String ssid = prefs.getString("ssid", WIFI_SSID);
  String pass = prefs.getString("pass", WIFI_PASS);
  prefs.end();

  WiFi.setHostname(HOSTNAME);
  WiFi.setAutoReconnect(true);
  if (ssid.length()) {
    WiFi.mode(WIFI_STA);
    WiFi.begin(ssid.c_str(), pass.c_str());
    logf("wifi: connecting to %s", ssid.c_str());
    for (int i = 0; i < 40 && WiFi.status() != WL_CONNECTED; i++) delay(500);
  }
  if (WiFi.status() == WL_CONNECTED) {
    WiFi.setSleep(false);  // keeps UDP/LX200 latency low
    logf("wifi: connected, IP %s", WiFi.localIP().toString().c_str());
  } else {
    // AP stays up alongside STA, which keeps retrying in the background
    WiFi.mode(ssid.length() ? WIFI_AP_STA : WIFI_AP);
    WiFi.softAP(AP_SSID, AP_PASS);
    logf("wifi: access point '%s' (pass '%s'), IP %s", AP_SSID, AP_PASS, WiFi.softAPIP().toString().c_str());
  }
}

// ---------------------------------------------------------------- web UI

static const char PAGE_HEAD[] PROGMEM =
    "<!doctype html><html><head><meta charset=utf-8><meta name=viewport content='width=device-width,initial-scale=1'>"
    "<title>StarMount</title><style>body{font-family:sans-serif;max-width:760px;margin:20px auto;padding:0 16px;"
    "background:#111;color:#eee}a{color:#8cf}pre{background:#000;padding:8px;overflow:auto;max-height:60vh}"
    "input,button{padding:6px;margin:4px 0}td{padding:2px 12px 2px 0}</style></head><body><h1>StarMount</h1>"
    "<p><a href=/>mount</a> | <a href=/sys>system</a> | <a href=/log>log</a> | <a href=/cmd>command</a> | <a href=/wifi>wifi</a> | "
    "<a href=/update>firmware</a></p>";

// Per-task stack headroom and CPU time (FreeRTOS run-time stats, microsecond counter).
// CPU load = delta of runtime between two calls; idle tasks give the free share per core.
static String jsonTasks() {
  UBaseType_t n = uxTaskGetNumberOfTasks();
  TaskStatus_t *t = (TaskStatus_t *)malloc(n * sizeof(TaskStatus_t));
  if (!t) return "{}";
  uint32_t total;
  n = uxTaskGetSystemState(t, n, &total);
  String s = "{\"total_us\":" + String(total) + ",\"min_free_heap\":" + String(ESP.getMinFreeHeap()) +
             ",\"heap\":" + String(ESP.getFreeHeap()) + ",\"tasks\":[";
  for (UBaseType_t i = 0; i < n; i++) {
    int core = t[i].xCoreID == tskNO_AFFINITY ? -1 : (int)t[i].xCoreID;
    char b[160];
    snprintf(b, sizeof(b), "%s{\"name\":\"%s\",\"core\":%d,\"prio\":%u,\"stack_free\":%lu,\"run_us\":%lu}",
             i ? "," : "", t[i].pcTaskName, core, (unsigned)t[i].uxCurrentPriority,
             (unsigned long)t[i].usStackHighWaterMark, (unsigned long)t[i].ulRunTimeCounter);
    s += b;
  }
  free(t);
  return s + "]}";
}

static String jsonStatus() {
  MountStats s = mountStats();
  const esp_partition_t *part = esp_ota_get_running_partition();
  char buf[512];
  snprintf(buf, sizeof(buf),
           "{\"uptime_s\":%lu,\"heap\":%lu,\"psram\":%lu,\"rssi\":%d,\"ip\":\"%s\",\"partition\":\"%s\","
           "\"usb_host\":%s,\"mount_connected\":%s,\"mount\":\"%s\",\"commands\":%lu,\"timeouts\":%lu,"
           "\"connects\":%lu}",
           millis() / 1000, (unsigned long)ESP.getFreeHeap(), (unsigned long)ESP.getFreePsram(), WiFi.RSSI(),
           WiFi.status() == WL_CONNECTED ? WiFi.localIP().toString().c_str() : WiFi.softAPIP().toString().c_str(),
           part ? part->label : "?", usbHostActive ? "true" : "false", mountConnected() ? "true" : "false",
           mountInfo().c_str(), (unsigned long)s.commands, (unsigned long)s.timeouts, (unsigned long)s.connects);
  return buf;
}

static void handleRoot() {
  String html = FPSTR(PAGE_HEAD);
  html += F("<table id=t></table><p>");
  html += usbHostActive ? F("<a href='/usbhost?enable=0'>Disable USB host on next boot</a>")
                        : F("<a href='/usbhost?enable=1'>Enable USB host on next boot</a>");
  html += F(" | <a href=/reboot>reboot</a></p><script>async function r(){const s=await(await fetch('/api/status'))"
            ".json();t.innerHTML=Object.entries(s).map(([k,v])=>`<tr><td>${k}</td><td>${v}</td></tr>`).join('')}"
            "r();setInterval(r,1000);fetch('/api/boots').then(x=>x.json()).then(b=>{bl.textContent="
            "b.boots.map(x=>`#${x.no} ${x.at||'?'}  ${x.reason}  (previous ran ${x.previous_ran_s} s)`).join('\\n')+"
            "'\\n\\nmount USB:\\n'+b.mount_usb.map(x=>`boot #${x.boot} +${x.uptime_s}s ${x.at||''} ${x.event}`).join('\\n')})"
            "</script><h2>Boots and power</h2><pre id=bl></pre></body></html>");
  web.send(200, "text/html", html);
}

static void handleCmd() {
  if (!web.hasArg("c")) {
    String html = FPSTR(PAGE_HEAD);
    html += F("<p>Raw SkyWatcher motor command, e.g. <code>:e1</code> (version), <code>:j1</code> (RA position), "
              "<code>:f1</code> (status). The trailing \\r is added for you.</p><form><input name=c value=':e1'> "
              "<button>send</button></form><pre id=o></pre><script>document.forms[0].onsubmit=async e=>{e.preventDefault();"
              "o.textContent=await(await fetch('/cmd?c='+encodeURIComponent(c.value))).text()}</script></body></html>");
    web.send(200, "text/html", html);
    return;
  }
  String c = web.arg("c");
  if (!c.endsWith("\r")) c += "\r";
  char resp[64];
  uint32_t t0 = micros();
  int n = mountCmd(c.c_str(), c.length(), resp, sizeof(resp));
  uint32_t dt = micros() - t0;
  if (n < 0) {
    web.send(504, "text/plain", "no reply from mount\n");
    return;
  }
  resp[strcspn(resp, "\r")] = 0;
  web.send(200, "text/plain", String(resp) + "   (" + String(dt / 1000.0, 1) + " ms)\n");
}

static void handleWifi() {
  if (web.method() == HTTP_POST) {
    prefs.begin("wifi", false);
    prefs.putString("ssid", web.arg("ssid"));
    prefs.putString("pass", web.arg("pass"));
    prefs.end();
    web.send(200, "text/plain", "saved, rebooting\n");
    delay(500);
    bootlog::beforeRestart();
    ESP.restart();
  }
  String html = FPSTR(PAGE_HEAD);
  html += F("<form method=post><p>SSID<br><input name=ssid></p><p>Password<br><input name=pass type=password></p>"
            "<button>save &amp; reboot</button></form></body></html>");
  web.send(200, "text/html", html);
}

static void handleUpdatePage() {
  String html = FPSTR(PAGE_HEAD);
  html += F("<p>Upload <code>.pio/build/usb/firmware.bin</code></p><form method=post enctype=multipart/form-data>"
            "<input type=file name=fw accept=.bin> <button>flash</button></form></body></html>");
  web.send(200, "text/html", html);
}

static void handleUpdateUpload() {
  HTTPUpload &up = web.upload();
  if (up.status == UPLOAD_FILE_START) {
    logf("ota(http): receiving %s", up.filename.c_str());
    if (!Update.begin(UPDATE_SIZE_UNKNOWN)) logf("ota(http): %s", Update.errorString());
  } else if (up.status == UPLOAD_FILE_WRITE) {
    if (Update.write(up.buf, up.currentSize) != up.currentSize) logf("ota(http): %s", Update.errorString());
  } else if (up.status == UPLOAD_FILE_END) {
    if (Update.end(true)) logf("ota(http): %u bytes written", up.totalSize);
    else logf("ota(http): %s", Update.errorString());
  }
}

static void handleUpdateDone() {
  bool ok = !Update.hasError();
  web.send(ok ? 200 : 500, "text/plain", ok ? "OK, rebooting\n" : String("failed: ") + Update.errorString() + "\n");
  if (ok) {
    delay(500);
    bootlog::beforeRestart();
    ESP.restart();
  }
}

static void webBegin() {
  web.on("/sys", handleRoot);
  dashboardBegin(web);
  web.on("/api/status", [] { web.send(200, "application/json", jsonStatus()); });
  web.on("/api/tasks", [] { web.send(200, "application/json", jsonTasks()); });
  web.on("/api/boots", [] { web.send(200, "application/json", bootlog::json()); });
  // Debug: feed NMEA sentences as if the GPS sent them (one per line, POST body "nmea")
  web.on("/api/gps_nmea", HTTP_POST, [] {
    String body = web.arg("nmea");
    int n = 0, start = 0;
    while (start < (int)body.length()) {
      int end = body.indexOf('\n', start);
      if (end < 0) end = body.length();
      String line = body.substring(start, end);
      line.trim();
      if (line.length()) {
        gps::inject(line.c_str());
        n++;
      }
      start = end + 1;
    }
    web.send(200, "application/json", "{\"lines\":" + String(n) + "}");
  });
  web.on("/log", [] { web.send(200, "text/plain; charset=utf-8", netlogHistory()); });
  web.on("/cmd", handleCmd);
  web.on("/wifi", handleWifi);
  web.on("/update", HTTP_GET, handleUpdatePage);
  web.on("/update", HTTP_POST, handleUpdateDone, handleUpdateUpload);
  web.on("/usbhost", [] {
    bool enable = web.arg("enable") == "1";
    prefs.begin("sys", false);
    prefs.putBool("usbhost", enable);
    prefs.end();
    web.send(200, "text/plain", String("USB host ") + (enable ? "enabled" : "disabled") + " from next boot\n");
  });
  web.on("/reboot", [] {
    web.send(200, "text/plain", "rebooting\n");
    delay(500);
    bootlog::beforeRestart();
    ESP.restart();
  });
  web.begin();
  MDNS.addService("http", "tcp", 80);
}

// ---------------------------------------------------------------- OTA

static void otaBegin() {
  ArduinoOTA.setHostname(HOSTNAME);
#ifdef OTA_PASS
  ArduinoOTA.setPassword(OTA_PASS);
#endif
  ArduinoOTA.onStart([] { logf("ota: start"); });
  ArduinoOTA.onEnd([] {
    logf("ota: done, rebooting");
    bootlog::beforeRestart();
  });
  ArduinoOTA.onError([](ota_error_t e) { logf("ota: error %u", e); });
  ArduinoOTA.begin();  // also starts mDNS as starmount.local
}

// ---------------------------------------------------------------- main

void setup() {
  Serial.begin(115200);
  pinMode(BOOT_BUTTON, INPUT_PULLUP);
  netlogBegin();
  const esp_partition_t *part = esp_ota_get_running_partition();
  logf("StarMount booting from %s, built " __DATE__ " " __TIME__, part ? part->label : "?");

  settingsLoad();
  bootlog::begin();
  persist::begin();
  wifiBegin();
  clockBegin();
  otaBegin();
  webBegin();
  synscanUdpBegin();  // raw motor access for debugging; don't use while the RA task is driving
  ra::begin();
  dec::setBacklash(settings.decBacklash);
  dec::begin();
  dec::setInverted(settings.pierEast, true);
  mount::begin();
  mount::applyDecSettings();
  onstep::begin();
  gps::begin();

  // A hang (e.g. starved idle tasks) reboots instead of silently killing Wi-Fi
  esp_task_wdt_config_t wdt = {.timeout_ms = 15000, .idle_core_mask = 0b11, .trigger_panic = true};
  if (esp_task_wdt_reconfigure(&wdt) != ESP_OK) esp_task_wdt_init(&wdt);

  // Recovery window: OTA always gets a chance before the USB host starts, and
  // holding BOOT skips the USB host for this boot.
  prefs.begin("sys", false);
  bool usbHostEnabled = prefs.getBool("usbhost", true);
  prefs.end();
  bool bootHeld = false;
  for (uint32_t t0 = millis(); millis() - t0 < RECOVERY_WINDOW_MS;) {
    if (digitalRead(BOOT_BUTTON) == LOW) bootHeld = true;
    ArduinoOTA.handle();
    web.handleClient();
    netlogLoop();
    delay(10);
  }
  if (!usbHostEnabled || bootHeld) {
    logf("usb: host NOT started (%s)", bootHeld ? "BOOT held" : "disabled in settings");
  } else {
    logf("usb: starting host on the OTG port");
    mountUsbBegin();
    usbHostActive = true;
  }

  esp_ota_mark_app_valid_cancel_rollback();
  logf("ready: http://%s.local  onstep/lx200 :%u :9999  telnet log :23  synscan udp :11880", HOSTNAME,
       settings.lx200Port);
}

void loop() {
  ArduinoOTA.handle();
  web.handleClient();
  netlogLoop();
  bootlog::tick();
  delay(2);
}

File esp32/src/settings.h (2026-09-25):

#pragma once
#include <Arduino.h>

// Runtime settings persisted in NVS. Defaults match lx200.py's CONFIGURATION block.
struct Settings {
  double lat = 40.8728;
  double lonEast = 14.4377;
  double utcOffset = 0;          // hours, local = UTC + utcOffset (from :SG or the browser)
  bool decAxisReversed = false;  // DEC_AXIS_REVERSED
  bool flipRaGuiding = false;    // FLIP_RA_GUIDING_ON_MERIDIAN
  bool pierEast = false;         // PIER_EAST_SIDE: inverts the DEC motor direction (:CP)
  uint16_t lx200Port = 5001;     // SERVER_PORT (OnStep/LX200 commands; 9999 is served too)
  double raEastLimit = 0;        // HA where the RA register window starts (deg, <= 0); see ra::offset()
  int32_t decBacklash = 250;     // DEC gear play in steps (plate-solve measured ~250-270)
  // Flipped branch: tracking goes on this many minutes past the meridian (OnStep :SXEA),
  // capped by the register overflow (ra::trackMax())
  int32_t raWestMinutes = 120;
  int32_t horizonLimit = -30;    // GoTo refused below this altitude (deg, OnStep :Sh, -30..30)
  int32_t overheadLimit = 90;    // GoTo refused above this altitude (deg, OnStep :So, 60..90)
  // PEC may start playing only before guiding begins for the target (no guide pulse since
  // boot or the last GoTo); false: after 60 s without pulses (a guiding pause is enough)
  bool pecStrict = true;
  bool refraction = true;        // refraction-compensated RA tracking (OnStep :Tr / :Tn)
  double guideRate = 0.5;        // pulse-guide rate, x sidereal, both axes (0.1..0.9)
  double decAxisMin = -180;      // DEC mechanical limits, deg of the DEC axis model (-180..180 = none)
  double decAxisMax = 180;
  bool gpsEnabled = true;        // NMEA GPS on UART1 (RX 17, TX 18, 9600 baud)
  bool gpsSetsSite = true;       // a 3D fix updates lat/lon
};

extern Settings settings;

void settingsLoad();
void settingsSave();

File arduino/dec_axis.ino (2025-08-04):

#include <AccelStepper.h>
// This is the arduino code for controlling the NEMA17 motor, connect the easy driver https://www.schmalzhaus.com/EasyDriver/ to the pin 2 and 3 of the arduino.
// Optionally, you can also connect an st4 wires to the 4 and 5 pin, this togheter with the Star Adventurer guiding port will enable you to guide from the camera itself (not really needed here).

// Define the stepper motor connections and interface type
#define STEP_PIN 2
#define DIR_PIN 3
#define DEC_PLUS_PIN 4
#define DEC_MINUS_PIN 5

// Create an instance of the AccelStepper class
AccelStepper stepper(AccelStepper::DRIVER, STEP_PIN, DIR_PIN);

// Steps for one full rotation
const long stepsPerRevolution = 585600;

// Sidereal rate in steps per second
const float siderealStepsPerSecond = 6.796; // Calculated earlier

// DEC motion states
bool dec_plus = false;
bool dec_minus = false;
bool meade = false;
bool movingToTarget = false;

// LX200 variables
long targetDecPosition = 292800;
long currentDecPosition = 292800;
float slewSpeed = siderealStepsPerSecond * 128ul; // Slew speed multiplier
float st4Speed = siderealStepsPerSecond * 8ul; // ST4 movement speed
float guideSpeed = siderealStepsPerSecond; // ST4 movement speed

// Serial input buffer
char inputBuffer[20];
int inputIndex = 0;

void setup() {
	Serial.begin(115200);
	pinMode(DEC_PLUS_PIN, INPUT_PULLUP);
	pinMode(DEC_MINUS_PIN, INPUT_PULLUP);
	pinMode(LED_BUILTIN, OUTPUT);

	// Initialize the stepper
	stepper.setMaxSpeed(slewSpeed);
	stepper.setSpeed(0);
	stepper.setCurrentPosition(currentDecPosition);
	digitalWrite(LED_BUILTIN, LOW);
}

void loop() {
	// Update the current DEC position
	currentDecPosition = stepper.currentPosition();

	// Check for manual ST4 inputs if not in meade mode
	if(!meade){
	handleSt4Inputs();
	}

	// Process LX200 commands from serial input
	processSerialInput();

	stepper.runSpeed();
	// Run the stepper to the target position if needed
	if (movingToTarget) {
	  if (stepper.distanceToGo()==0) {
	      movingToTarget = false;
	      //Serial.println("DONE");
	      stepper.setSpeed(0);
	  }
	}
	}
	void stop_everything(){
	  stepper.stop();
	  movingToTarget = false;
	  targetDecPosition = currentDecPosition;
	  //stepper.moveTo(currentDecPosition);
	  stepper.setSpeed(0);  
	}
	void handleSt4Inputs() {
	if (!digitalRead(DEC_PLUS_PIN)) {
	  if (!dec_plus) {
	      stepper.setSpeed(st4Speed);
	  }
	  dec_plus = true;
	  dec_minus = false;
	} else if (!digitalRead(DEC_MINUS_PIN)) {
	  if (!dec_minus) {
	      stepper.setSpeed(-st4Speed);
	  }
	  dec_plus = false;
	  dec_minus = true;
	} else {
	  if (dec_plus || dec_minus) {
	      stepper.stop();
	      stepper.setSpeed(0);
	  }
	  dec_plus = false;
	  dec_minus = false;
	}
}

void processSerialInput() {
	while (Serial.available() > 0) {
	  char c = Serial.read();
	  if (c == '#') {
	      handleCommand(String(inputBuffer));
	      memset(inputBuffer, 0, sizeof(inputBuffer));
	      inputIndex = 0;
	  } else {
	      inputBuffer[inputIndex++] = c;
	      if (inputIndex >= sizeof(inputBuffer)) {
		  inputIndex = 0; // Prevent buffer overflow
	      }
	  }
	}
}

void handleCommand(String command) {
	if (command.startsWith(":Q")) {
	  stop_everything();
	  Serial.println("#");
	} else if (command.startsWith(":Mn")) {
	  stop_everything();
	  stepper.setSpeed(guideSpeed);
	  Serial.println("#");
	} else if (command.startsWith(":Ms")) {
	  stop_everything();
	  stepper.setSpeed(-guideSpeed);
	  Serial.println("#");
	} else if (command.startsWith(":Gd")) {
	  Serial.println(currentDecPosition);
	  //Serial.println("#");
	} else if (command.startsWith(":Y")) {
	  meade = true;
	  Serial.println("#");
	  digitalWrite(LED_BUILTIN, HIGH);
	} else if (command.startsWith(":X")) {
	  meade = false;
	  stop_everything();
	  Serial.println("#");
	  digitalWrite(LED_BUILTIN, LOW);
	} else if (command.startsWith(":CP")) {
	  Serial.println("#");
	  stepper.setPinsInverted(true, false, false);
	} else if (command.startsWith(":MS")) {
	  if(targetDecPosition != currentDecPosition){
	    stepper.moveTo(targetDecPosition);
	    if (targetDecPosition>currentDecPosition){
	      stepper.setSpeed(slewSpeed);
	    }else{
	      stepper.setSpeed(-slewSpeed);
	    }
	    movingToTarget = true;
	  }
	  Serial.println("#");
	} else if (command.startsWith(":Sd")) {
	  targetDecPosition = command.substring(3).toInt(); //position in steps
	  Serial.println("#"); // Acknowledge
	} else if (command.startsWith(":CM")) { //sync
	  stepper.setCurrentPosition(targetDecPosition);
	} else if (command.startsWith(":D")){
	  if(movingToTarget){
	      Serial.println("1");
	  } else {
	      Serial.println("0");
	  }
	} else {
	  Serial.println("Got "+ command + " unknown"); // Unknown command
	}
}

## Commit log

2025-08-04 first push
    [Nema17Knob.stl, Nema17MotorHolder.stl, StarAdventurerDeclinationKnobMod.stl]
2025-08-13 switch to the old script for now
2026-09-22 Add ESP32-S3 mount controller firmware (RA on ESP, DEC simulated)
    PlatformIO project in esp32/ that turns an ESP32-S3 into the mount controller:
    - USB host driver for the Star Adventurer's PL2303 on the OTG port
    - OTA updates, persistent network log (telnet :23, /log), SynScan UDP bridge
    - RA axis controller ported from lx200.py (tracking, goto, guiding, sync,
    meridian flip) with the measured firmware quirks handled: J keep-alive for
    auto-stops, non-invasive restarts so guide pulses are never disturbed,
    HA/register safety limits
    - LX200 server on port 5001 with lx200.py-compatible replies, DEC simulated
    - Dashboard, NTP/LX200/browser clock, NVS settings
    - Host unit tests of the astro m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
    [main.cpp]
2026-09-22 Drive the DEC stepper from the ESP32 (replaces the separate DEC controller)
    - dec_axis: EasyDriver on STEP 6 / DIR 5 / EN 38 (active low, auto-disabled
    when idle) with hardware step generation (FastAccelStepper); position kept
    across soft resets/OTA since the stepper is open loop
    - guide pulses are exact step moves (rate x duration, fractional steps carried
    over) instead of timed stops, which overshot by the queued steps
    - LX200 layer ports lx200.py's DEC logic: set_dec/steps_to_coord with the
    meridian_flipped ^ DEC_AXIS_REVERSED reversal, N/S swap when reversed,
    :MS/:Q/:CM/:D; PIER_EAST_SIDE setting inverts the motor direction
    - dashboard: DEC steps, pier-east setting, DEC test bu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
    [dec_axis.cpp, main.cpp]
2026-09-22 Detect a freshly powered mount by a register near zero, not exactly zero
    The Star Adventurer starts tracking on its own at power-on, so by the time the
    ESP connects the register is a few counts past 0 and the home sync was skipped,
    leaving the axis right at the zero edge the firmware can't cross.
    [ra_axis.cpp]
2026-09-22 Add esp32 README (setup, architecture, quirks, differences from lx200.py) and HIL tests
2026-09-25 Add sensor, pose-awareness and polar-alignment design notes
    GPS, base LSM6DSV+QMC6309 and hot-shoe MPU6500: what they can and can't give,
    polar alignment tiers from sky-less (~0.5-1 deg) to two plate solves (~1'),
    IMU authority rules so guiding is never disturbed, power-bank risks, hardware
    notes and revised priorities.
2026-09-25 DEC backlash compensation, 0.5x DEC guide rate, sky test tools
    Plate-solved tests through a window measured ~250 steps (0.3 deg) of DEC
    backlash: GoTos ending south were 17-18' short and the first ~4 guide pulses
    after a reversal did nothing. dec_axis now keeps the gear position apart from
    the motor position, runs the play out at slew speed on reversals (pulses
    included) and ends GoTos moving north. Backlash is a dashboard/NVS setting.
    After the change DEC GoTos land within 0.4-1.4' in both directions.
    lx200.py's 6.796 steps/s DEC 'sidereal' rate was really 2x sidereal; the DEC
    guide rate is now 0.5x like RA.
    tools/sky: polar alignment from two solves around an RA move, mount tests
    (DEC sc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
    [astrometry.cfg]
2026-09-25 RA guide directions follow ASCOM (west = faster); document RA window, branch check, collision layers
    :Mgw slowed RA (the scope moved east), inherited from lx200.py. Measured on
    the sky and against the register: west is now 1.5x, east 0.5x sidereal. PHD2
    calibrations made with the old firmware need redoing.
    Design notes: a single solve's field rotation (or the camera accelerometer)
    tells which DEC branch the mount is on; collision protection in layers
    (taught limits, accelerometer tilt rules, gyro stall detection during slews);
    moving the RA register window to HA -30..+150 so the flip happens 2 h before
    the meridian instead of at transit; the missing west-limit stop while tracking.
    Also the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
    [ra_axis.cpp, ra_axis.h]
2026-09-25 README: RA periodic error measurement
    Claude-Session: https://claude.ai/code/session_019T6LigWjUFbXCz1FUWDR3j
    [lx200.py]
2026-09-25 Configurable RA east limit, stop at the tracking limit, sync keeps the branch
    - register = HA - east limit + 2 (dashboard setting ra_east, default 0 keeps
    lx200.py's behaviour; -30 moves the flip to 2 h before the meridian).
    Changing it shifts the register so the position keeps its meaning.
    - GoTo window [2, 182] on both branches: lx200.py's 180 threshold left
    targets that flipped to a register below 2 and were refused.
    - Tracking continues past the window and stops at register 235, before the
    24-bit overflow; the dashboard shows STOPPED AT RA LIMIT.
    - :Sr/:Sd only store the request. :MS picks the window's branch, :CM the
    branch nearest the current register: a sync past the window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
    [ra_axis.cpp, ra_axis.h, settings.h]
2026-09-25 OnStep front-end: command subset captured from the INDI OnStep driver
    The real indi_lx200_OnStep (INDI 2.2.0) was pointed at a logging OnStepX
    stand-in and driven through connect, GoTo, sync, guide pulses, moves,
    tracking, time/location and park. Reply formats come from the OnStepX source.
    Findings: a 13-command status poll (:GU#, :Gm# pier side, :GXE9/:GXEA
    meridian limits = our RA window, :%BD backlash, ...); string-reply commands
    must get a real answer or the driver stalls 2-5 s and reconnects; the driver
    sends high-precision and 60-second coordinates (:Sr17:23:60.00#).
    Claude-Session: https://claude.ai/code/session_019T6LigWjUFbXC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
2026-09-25 Replace the LX200 front-end with an OnStepX-compatible one
    OnStepX's command set is a superset of LX200, so one front-end serves the
    INDI/ASIAIR OnStep drivers, NINA (ASCOM OnStep) and plain LX200 clients, on
    port 5001 (the old one) and 9999. It reports pier side (:Gm#, :GU#), the
    meridian limits from the RA window (:GXE9/:GXEA), DEC backlash (:%BD),
    tracking on/off (:Te/:Td) and answers "not supported" for focuser, rotator,
    weather, park and other track rates.
    - mount: the target, flip branch, guide flags and GoTo/sync/move actions
    move out of the protocol layer, so every front-end shares one flip flag.
    - lib/core: OnStep parsers/formatters (fractional seconds, the INDI
    driver's 17:23: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
    [main.cpp]
2026-09-25 PEC, GPS, limits, tracking rates and refraction over the OnStep protocol
    PEC (OnStep $QZ + - / Z ! ?, :VR/:WR, :GXE6/7/8): one correction per worm
    segment (598 x ~1 sidereal s, 144-tooth worm) recorded from RA guide pulses,
    smoothed, mean removed; played back by the RA step period with the rounding
    carried over. The worm phase follows register rewrites and is saved to NVS,
    surviving power cycles. Playback never starts under an active guider:
    strict (default) = only before guiding begins for the target (reset by a
    GoTo), or after 60 s without pulses. HIL: table correlation 0.978, playback
    correlation 0.999, gain 1.04, 5.4 counts rms.
    GPS boilerplate: NMEA RMC/GGA on UART1 (RX 17, TX 18, 9600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
    [dec_axis.cpp, gps.cpp]
2026-09-26 RA rate calibration: the mount's register runs at exactly timerHz/T1
    Measured the register rate against raw step periods T1 280-439, timed with
    the ESP's own register-read timestamp (new counts_ms in /api/status): the
    ratio to timerHz/T1 is 1.0000 within 0.04%. The earlier 0.36% lunar error
    and PEC's 1.04 playback gain were laptop-side HTTP timing, so no calibration
    model is needed; T1 is now rounded instead of truncated.
    features_test.py times rates on the ESP and checks lunar within 0.15%
    (passes, all checks). rate_calibration.py and its data are kept.
    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
    [rate_calibration.csv]
2026-09-26 Manual-move speeds (:R0-:R9) and a boot/power log in NVS
    Manual moves take OnStep's rates (0.25x..48x, half max, max; Meade
    :RG/:RC/:RM/:RS). RA below 1x changes the tracking speed; from 1x the motor
    runs west or reversed east with the slew keep-alive (max ~64x measured),
    stops at the register limits and aborts a PEC recording. DEC runs up to 256x
    with backlash take-up and axis limits. The status shows MOVING instead of
    GUIDING. HIL move_test.py passes.
    /api/boots (and /sys): the last 10 boots with reset reason and how long the
    previous boot ran (saved every 5 min and before planned restarts), and the
    last 10 mount USB connects/disconnects. The USB task only records in RAM;
    loop() writes NV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
    [dec_axis.cpp, main.cpp]
2026-09-26 Plan: automatic DEC backlash and scale from the camera IMU gyro at startup
    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
2026-09-26 Plan: measure DEC backlash at every GoTo (final reversal), not only at startup
    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
2026-09-26 RA without a register limit; persistent state struct; verified register writes
    - The model works in the axis angle; the SA register = axis angle + a
    persisted shift, re-centred to 8 deg only when the motor is stopped anyway
    (sync, home, GoTo start/end, mid-slew for slews longer than the band), never
    while tracking (after ~15 h tracking stops at the band end). RA limits are
    physical only: east limit and west tracking stop (default 2 h, max 4 h).
    - Register writes wait for the stop, verify by read-back and retry with a hard
    stop: the SA rejected :E twice in 20 writes after fast moves, which before
    could silently drop a sync. A failed write marks the position untrusted.
    - Sync keeps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
    [dec_axis.cpp, main.cpp]
